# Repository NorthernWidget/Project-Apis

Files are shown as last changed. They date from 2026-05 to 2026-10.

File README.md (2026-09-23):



# Project-Apis
Design files for a support and interface unit for the Garmin LiDAR Lite.

## Contents

- [Namesake](#namesake)
- [Technical specifications](#technical-specifications)
  - [Electronic hardware](#electronic-hardware)
  - [Electronic software and firmware](#electronic-software-and-firmware)
- [Assembly](#assembly)
  - [Producing circuit boards](#producing-circuit-boards)
  - [Populating circuit boards](#populating-circuit-boards)
  - [Reflowing circuit boards](#reflowing-circuit-boards)
  - [Debugging circuit boards](#debugging-circuit-boards)
- [Firmware](#firmware)
  - [Downloading and installing the Arduino IDE](#downloading-and-installing-the-arduino-ide)
  - [AVR ISP](#avr-isp)
  - [Uploading the firmware](#uploading-the-firmware)
- [Writing a program to connect to the Apis](#writing-a-program-to-connect-to-the-apis)
  - [Very simple Arduino code](#very-simple-arduino-code)
  - [Northern Widget Margay code](#northern-widget-margay-code)
  - [Northern Widget Resnik code](#northern-widget-resnik-code)
- [Register map and firmware internals](#register-map-and-firmware-internals)
- [Housing and cabling](#housing-and-cabling)
  - [Parts required](#parts-required)
  - [Assembly](#assembly-1)
- [Field installation](#field-installation)
  - [Mast construction](#mast-construction)
- [Acknowledgments](#acknowledgments)

## Namesake

### Current: Apis

Rapid detector eyes

With its internal guidance system and compound eyes, the honeybee can obtain orientation and range while seeing in slow motion. Those rapid eyes feel perfect for a laser, and though the bee doesn't have one – it senses distance through parallax instead – just imagine if it did.

### Former: Symbiont-LiDAR

Symbiosis

***The symbiont.*** *Lichens, like this Reindeer Lichen found in northeastern
Minnesota, are a symbiosis between fungi and algae. Our symbiosis is between
silicon, copper, aluminum, and laser. But be it nature or machine, some
partnerships are truly mutual in their benefits. Photo by Homer Edward Price.*

The [LiDAR Lite](https://buy.garmin.com/en-US/US/p/578152/pn/010-01722-10) is a rangefinder from Garmin capable of returning distances to objects up to 40 m away. It is an effective sensor for water, snow, and ice levels, among other purposes. Extensive work to characterize the LiDAR Lite for environmental sensing of water levels has been performed by:

Paul, J. D., Buytaert, W., & Sah, N.(2020). A technical evaluation of lidar-based measurement of riverwater levels. *Water Resources Research*, *56*, e2019WR026810. https://doi.org/10.1029/2019WR026810

## Technical specifications

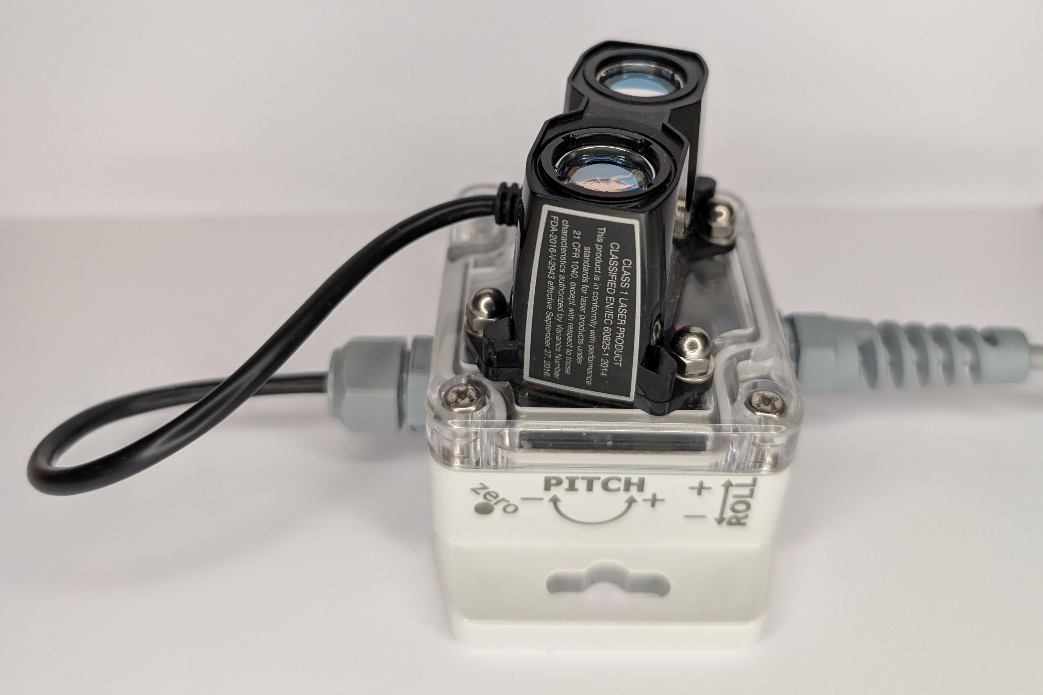
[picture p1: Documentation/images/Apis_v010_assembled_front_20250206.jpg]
Assembled Apis unit


***Assembled Apis unit.*** *The front face shows pitch and roll orientation conventions and the "zero" location (oval cutout, lower center) where the magnet is tapped to calibrate the accelerometer.*

### Electronic Hardware

* Microcontroller (computer) core
  * ATTiny1634
  * [Firmware](Firmware) written in Arduino-compatible C++
  * 12 MHz
* Sensors
  * Externally connected: [Garmin LiDAR Lite v3 HP](https://buy.garmin.com/en-US/US/p/578152/pn/010-01722-10)
  * On board
    * MEMS accelerometer to detect board angle
    * Hall-effect sensor to for user to trigger with a magnet after providing a known angle to the accelerometer. This corrects for offset errors in the accelerometer, significantly improving its angular accuracy.
* Connections and communications protocols
  * [LiDAR Lite v3 HP](https://buy.garmin.com/en-US/US/p/578152/pn/010-01722-10)
    * 6-pin screw-terminal header
    * Switchable 5V power supply
    * I2C
  * Data logger
    * Power in and Ground
    * Digital communications
      * I2C
* Power
  * Voltage limits: 3.3 ~ 5.5V
  * Power consumption: ~0.5mA @ 4.5V, take reading every 60 seconds, then power down
  * Power conditioning: Provides an onboard, high power, step up to 5V to allow for interface to 3.3V loggers
* Fault recovery: Using intermediate system to emulate an I2C connection prevents a global lockup of the logger system
* Status LED
* Open-source licensing via CC BY-SA 4.0

Apis board

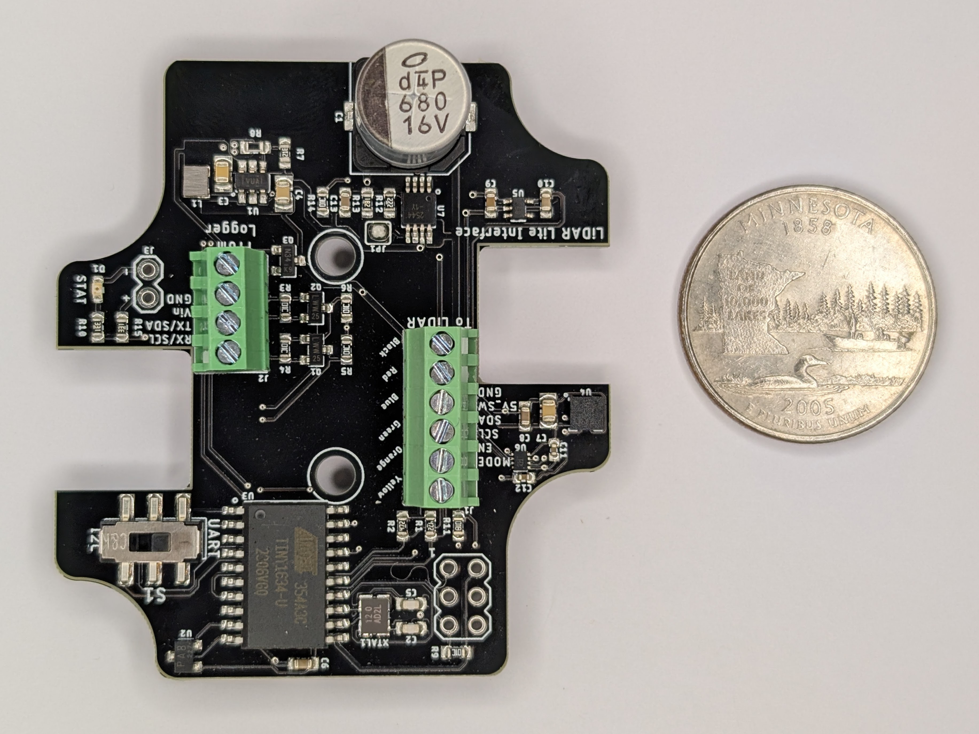
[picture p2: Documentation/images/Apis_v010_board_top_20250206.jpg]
Apis board top


***Apis v0.1 board, top side.*** *Minnesota quarter (24.3 mm diameter) for scale.*

### Electronic Software and Firmware

* Programmable using the Arduino IDE https://www.arduino.cc/en/main/software
* [Firmware](Firmware/Apis_LiDAR_Firmware) available in this repository.
* [Software](https://github.com/NorthernWidget/Apis_Library) to use the Apis with Arduino-compatible devices
* Open-source licensing via GNU GPL 3.0

## Assembly

Rendered image of assembled LiDAR unit

Assembling this sensor is possible by hand with sufficient skill and the following tools:
* Temperature-controlled soldering iron
* Hot-air rework station
* Equipment for stenciling with solder paste
* ESD-safe tweezers and workstation
* Solder wick

Most of the components on this board are coarse enough in pitch that assembly by hand is expected to be relatively straightforward. However, if you are concerned about this, there are PCB assembly workshops located in many parts of the world.

### Producing circuit boards

We recommend having circuit boards produced by a reputable manufacturer. Many are located in China, India, and other countries worldwide. You will need to provide the Gerber files, available in this repository alongside the board design files.

### Populating circuit boards

Before placing components, you will need solder paste and a stencil. A stencil allows you to apply a controlled, even amount of paste to all pads at once. If you have access to a laser cutter, you can [create your own stencil](https://learn.adafruit.com/smt-manufacturing/laser-cut-stencils); otherwise, most PCB manufacturers offer stencil production as an add-on service. In a pinch, a solder-paste syringe works but increases the risk of bridged connections. Additional guidance on stenciling is available [here](https://www.sparkfun.com/tutorials/58).

Once paste is applied, use tweezers – or a pick-and-place machine if available – to place each component onto its pads in the correct orientation. Slight misalignment is acceptable; surface tension from the molten solder will help pull components into place during reflow.

### Reflowing circuit boards

Reflowing heats the solder paste until it flows and bonds components to the board. A basic introduction is available [here](https://learn.sparkfun.com/tutorials/electronics-assembly/reflow). Common methods include:

1. **Professional reflow oven** – the most consistent method
2. **Converted toaster oven** – affordable and effective; see [SparkFun's guide](https://www.sparkfun.com/tutorials/60) and many other online references
3. **Electric skillet** – surprisingly effective for simple boards; [guide here](https://www.sparkfun.com/tutorials/59)
4. **Hot-air rework station** – more labor-intensive but gives fine control; suitable for single boards or small runs; [guide here](https://learn.sparkfun.com/tutorials/how-to-use-a-hot-air-rework-station/all)

After reflow, clean up any bridged connections with **solder wick**.

### Debugging circuit boards

Inspect the board carefully after reflow. Look for bridged connections, cold joints, or components that shifted out of alignment. A multimeter is essential for checking continuity and identifying shorts. An oscilloscope or logic analyzer can help verify that the microcontroller, accelerometer, and I2C bus are functioning correctly. If you are new to debugging circuit boards, working with an electrical engineering student or professional – even for a single session – can save significant time.

## Firmware

### Downloading and installing the Arduino IDE

Go to https://www.arduino.cc/en/main/software. Choose the proper IDE version for your computer. For Windows, we suggest the non-app version to have more control over Arduino; this might change in the future. You will have to add custom libraries, so the web version will not work (at least, as of the time of writing). Download and install the Arduino IDE. Open it to begin the next steps.

### AVR ISP

To install firmware on the Apis board, you use the [2x3-pin 6-pin ICSP (also called ISP) header](https://www.digikey.com/product-detail/en/3m/929665-09-03-I/3M156313-06-ND/681796) with a special device called an "in-circuit system programmer" (or just "in-system programmer; yup, that's what the acronym stands for).

Many devices exist to upload firmware, including:
* The official [AVR ISP mkII](http://ww1.microchip.com/downloads/en/DeviceDoc/Atmel-42093-AVR-ISP-mkII_UserGuide.pdf) (no longer produced but available used)
* Using an [Arduino as an ISP](https://www.arduino.cc/en/tutorial/arduinoISP)
* The versatile [Olimex AVR-ISP-MK2](https://www.olimex.com/Products/AVR/Programmers/AVR-ISP-MK2/open-source-hardware)
* The [Adafruit USBtinyISP](https://www.adafruit.com/product/46)

### Uploading the firmware

Using this ISP, upload [the firmware sketch](Firmware/Apis_LiDAR_Firmware) to the board. To do so, follow these steps:

1. Open the Arduino IDE.
2. Follow [these instructions](https://github.com/SpenceKonde/ATTinyCore/blob/master/Installation.md) to install the [ATTinyCore board definitions](https://github.com/SpenceKonde/ATTinyCore)
3. Select [ATTiny1634](https://github.com/SpenceKonde/ATTinyCore/blob/master/avr/extras/ATtiny_1634.md) **(No bootloader)**
4. Plug your ISP of choice into your computer (via a USB cable) and onto the 6-pin header. There are two ways to place it on; the header is aligned such that the ribbon cable should be facing away from the board while programming. If this fails without being able to upload, try flipping the header around. This should both power the board and provide communications.
5. Go to Tools --> Programmer and select the appropriate programmer based on what you are using.
6. Go to Tools --> Burn Bootloader. Yes, we know that you just selected "ATTiny1634 (No bootloader)", but this step sets the fuses, which configure their internal oscillator and brown-out detection.
7. Go to Sketch --> Upload Using Programmer. After several seconds, you learn whether you succeeded or failed. Hopefully it worked!

Upload using programmer

***Uploading using the in-system programmer.***

***Important note for Linux users:*** You must supply permissions to the Arduino IDE for it to be able to use the ICSP, or you will have to run it using `sudo`. The former option is better; the latter is easier in the moment.

***Note: Be sure to download and/or update drivers for your ISP.***

## Writing a program to connect to the Apis

Once it is bootloaded and connected with a LiDAR Lite sensor, you should be able to use any standard Arduino device to connect to it and read its data.

### Very simple Arduino code

This code is intended for any generic Arduino system.

```c++
#include "Apis.h"

// Declare variables -- just as strings
String header;
String data;

// Instantiate class
Apis myLaser;

void setup(){
    // Begin Serial connection to computer at 38400 baud
    Serial.begin(38400);
    // Obtain the header just once
    header = myLaser.getHeader();
    // Print the header to the serial monitor
    Serial.println(header);
}

void loop(){
    // Take one reading every (10 + time to take reading) seconds
    // and print it to the screen
    myLaser.updateMeasurements();
    data = myLaser.getString();
    Serial.println(data);
    delay(10000); // Wait 10 seconds before the next reading, inefficiently
}
```

### Northern Widget Margay code

The [Margay data logger](github.com/NorthernWidget-Skunkworks/Project-Margay) is the lightweight and low-power open-source data-logging option from Northern Widget. It saves data to a local SD card and includes on-board status measurements and a low-drift real-time clock. We have written [a library to interface with the Margay](github.com/NorthernWidget-Skunkworks/Margay_Library), which can in turn be used to link the Margay with sensors.

```c++
#include "Margay.h"
#include "Apis.h"

// Declare variables -- just as strings
// Empty header to start; will include sensor labels and information
String header = "";
String data;

// Instantiate classes
Apis myLaser;
Margay Logger; // Margay v2.2

// I2CVals for Apis
uint8_t I2CVals[] = {0x50}; // DEFAULT

//Number of seconds between readings
uint32_t updateRate = 60;

void setup(){
    header = header + myLaser.getHeader();
    Logger.begin(I2CVals, sizeof(I2CVals), header);
    initialize();
}

void loop(){
    Logger.run(update, updateRate);
}

String update() {
    initialize();
    return myLaser.getString();
}

void initialize(){
    myLaser.begin();
}
```

### Northern Widget Resnik code

>> The Resnik/Okapi system uses a Particle Boron for cellular telemetry – the defining capability that distinguishes it from the Margay. That telemetry component is not yet shown here; the code below is currently identical to the Margay example. See [issue #21](https://github.com/NorthernWidget/Project-Apis/issues/21).

```c++
#include "Resnik.h"
#include "Apis.h"

// Declare variables -- just as strings
// Empty header to start; will include sensor labels and information
String header;
String data;

// Instantiate classes
Apis myLaser;
Resnik Logger;

// I2CVals for Apis
uint8_t I2CVals[] = {0x50}; // DEFAULT

//Number of seconds between readings
uint32_t updateRate = 60;

void setup(){
    header = header + myLaser.getHeader();
    Logger.begin(I2CVals, sizeof(I2CVals), header);
    initialize();
}

void loop(){
    Logger.run(update, updateRate);
}

String update() {
    initialize();
    return myLaser.getString();
}

void initialize(){
    myLaser.begin();
}
```

## Register map and firmware internals

The Apis firmware runs on an ATTiny1634 and exposes an I2C register map to the host logger, laid out per [NW-Device-Specification](https://github.com/NorthernWidget/NW-Device-Specification) Schema 1. The default I2C address is `0x41` (ASCII `'A'`); the address is stored in Page 0 and can be changed (see below).

The device exposes a flat, byte-addressable virtual address space. The controller writes a 1-byte starting address, then reads up to 32 bytes in one transaction; the firmware auto-increments. Pages are 32-byte aligned.

The map below is what the firmware on `master` implements (firmware patch 5, unreleased). Boards carrying the previous firmware (v0.1.x, the deployed 2019-era map) are described at the end of this section; a Schema 1 library will refuse them until they are reflashed and provisioned.

### Measurement loop

The firmware is on-demand: it idles (core in idle sleep, woken by an I2C address match or the Hall switch) until the controller writes the trigger bit, then

1. Clears the ready bit, reads the chip-select bits from the control register, and consumes the trigger
2. If the controller has written the readings-requested word (0x44–0x45) since the last trigger, latches it and notes the reading counter
3. If the LiDAR chip is selected and the LiDAR is off: closes the 5 V switch, waits ~20 ms for the rail (680 µF through the MIC2544 at its ~227 mA limit), raises enable, and polls the LiDAR for an I2C acknowledge and the health flag in its STATUS register (bit 5) for up to 100 ms; on timeout toggles enable once more; a second failure powers the LiDAR down and latches fault chip 0 kind 1 (no acknowledge) or 5 (not initialised). On success it writes the configured sensitivity
4. If the LiDAR chip is selected and powered: writes ACQ_COMMAND (any non-zero value starts a measurement on the v3HP), polls STATUS bit 0 (busy) until clear, and reads the 16-bit range and the signal strength. The LiDAR's mode pin is not used (see issue #24)
5. If the accelerometer chip is selected: reads the 3-axis accelerometer (LIS3DH) and the stored offsets
6. Loads status, fault code, and the reading counter, then sets the ready bit, with interrupts disabled so a page read never straddles the update
7. Powers the LiDAR down if the request was for a single reading (0 or 1) or the requested count is now complete; otherwise leaves it powered for the next trigger. A batch with no trigger for 2 s is abandoned: LiDAR off, fault chip 0 kind 2

Serial output (range and axes per reading) exists only when the sketch is compiled with `APIS_DEBUG` defined.

### Register map (firmware on `master` – Schema 1)

Three 32-byte pages. Page 0 (identity) is copied from EEPROM at boot; Page 1 (calibration) is copied from EEPROM byte for byte at boot and again after each zero (a blank word reads as 0); Page 2 (status and sensor data) lives in SRAM. Pages renumbered 2026-09-23 (spec 4c3b18d): calibration is Page 1 at 0x20, data Page 2 at 0x40.

**Page 0 (0x00–0x1F) – Identity (EEPROM 0xC0–0xDF, written by [NW-Provision](https://github.com/NorthernWidget/NW-Provision))**

```
Block 0 (0x00–0x07)   Core identity
  0x00        0x01              Schema (NW-Device-Specification v1)
  0x01–0x04   'A','p','i','s'   Device name (ASCII)
  0x05–0x07   0x00,0x00,0x00    Null padding

Block 1 (0x08–0x0F)   Version
  0x08        HW major          (from EEPROM)
  0x09        HW minor          (from EEPROM)
  0x0A        FW patch          written by the firmware into the served copy (FW_FW_PATCH),
                                so it always matches the code running; the CRC of the served
                                copy is recomputed
  0x0B–0x0D   0x00,0x00,0x00    Unused (combined repo)
  0x0E–0x0F   0x00,0x00         Reserved

Block 2 (0x10–0x17)   Serial number
  0x10–0x11   0x41,0x00         Board type ('A' = 0x41, hardware major 0; NW-Registry 0x4100)
  0x12–0x13   [provisioning]    Group ID
  0x14–0x15   [provisioning]    Unique ID
  0x16–0x17   0x00,0x00         FirmwareID (legacy, reserved)

Block 3 (0x18–0x1F)   Integrity + administration
  0x18–0x1C   0x00 ×5           Reserved
  0x1D        0x4E              Magic byte ('N')
  0x1E        [computed]        CRC-8/SMBUS of bytes 0x00–0x1D
  0x1F        0x41              I2C address (writable; 0xFF = use default 0x41)
```

If the CRC in EEPROM does not match, or the schema byte is not 0x01, the firmware still runs but sets the Report register to "unit: Page 0 checksum" (`0xE3`); the board needs provisioning.

**Page 2 (0x40–0x5F) – Status and sensor data (SRAM)**

Chip table (index for status fault bits, control chip-select bits, and the Report register):

| Index | Chip | Measurements |
|---|---|---|
| 0 | LiDAR Lite v3HP | range, signal strength |
| 1 | LIS3DH accelerometer | X, Y, Z |

```
Block 0 (0x40–0x47)   Universal block (NW-Device-Specification)
  0x40        Status            bit 0 ready; bit 1 LiDAR fault; bit 2 accelerometer fault;
                                bit 7 pan-fault. Read-only, live.
  0x41        Control           writable. bit 0 trigger a reading now (the firmware clears it
                                when the reading starts); bit 1 measure LiDAR; bit 2 measure
                                accelerometer (power-up: both set); bit 7 sleep – defined by
                                the spec, not yet implemented here (cleared by the firmware).
                                Any write to Control clears the Report register.
  0x42–0x43   Reading counter   uint16, little-endian, +1 each time ready is set; 0 at boot
  0x44–0x45   Readings          writable, uint16 little-endian: how many readings the controller will
              requested         trigger with the LiDAR held powered; 0 (boot value) = one per trigger,
                                powered down after each. A new write replaces the remainder.
  0x46        Config            writable. bits 1:0 LiDAR sensitivity mode (see below)
  0x47        Report            latched until the controller writes Control: the most recent report, a fault (its chip's status bit is set too) or a notice (no status bit): bits 7-5 chip (7 = the unit), bits 4-0 kind (1 no acknowledge, 2 timeout, 5 not initialised, 6 reset, 9 calibration stored, 10 batch abandoned).
                                bits 7–5 chip (0 LiDAR, 1 accelerometer, 7 unit);
                                bits 4–0 kind (1 no-acknowledge, 2 timeout, 3 Page 0 checksum,
                                5 not initialised, 6 reset since the controller last wrote Control)

Block 1 (0x48–0x4F)   LiDAR Lite
  0x48–0x49   Range [cm]        little-endian int16; -9999 on timeout
  0x4A        Signal strength   uint8
  0x4B–0x4F   Reserved

Block 2 (0x50–0x57)   Accelerometer
  0x50–0x51   Accel X           little-endian int16 (raw counts, >> 4)
  0x52–0x53   Accel Y           little-endian int16
  0x54–0x55   Accel Z           little-endian int16
  0x56–0x57   Accel temperature, the LIS3DH OUT_ADC3 word as read (low byte first): relative, 1 digit per °C in the high byte (patch 3)

Block 3 (0x58–0x5F)   0x58–0x59 zero generation, uint16 LE, the Page 1 value, served with every reading (patch 5)
  0x5A–0x5F   Reserved
```

Check bit 0 of 0x40 before using any measurement; if clear, the data registers are stale. Compare the reading counter with the last value read to know whether a new reading has happened since.

At boot the Report register reads `0xE6`, "unit: reset since the controller last wrote Control", so a controller can tell that the device restarted (and lost its volatile configuration) since it last configured it. The first write to Control clears it.

**Page 1 (0x20–0x3F) – Calibration (EEPROM 0xE0–0xFF)**

```
Block 0 (0x20–0x27)   Current zero: Offset X, Y, Z int16 LE; accel temperature word int16   (as today)
  0x20–0x21   Offset X          little-endian int16
  0x22–0x23   Offset Y          little-endian int16
  0x24–0x25   Offset Z          little-endian int16
  0x26–0x27   Accel temperature word when the offsets were taken (patch 3)
Block 1 (0x28–0x2F)   Previous zero, same form
Block 2 (0x30–0x37)   The zero before that, same form
Block 3 (0x38–0x3F)   0x38–0x39 zero generation, uint16 LE: zeros stored since manufacture (0 = never);
                      0x3A–0x3F reserved
```

Offsets are written when the Hall-effect switch is triggered with the magnet (the board's "set level" action). A never-written word (0xFFFF) reads as zero. Storing a zero (patch 5) shifts Block 1 to Block 2 and Block 0 to Block 1, writes the new zero into Block 0, and adds one to the generation, byte by byte with compare-before-write; the served page and the mirror at 0x58 follow at once, and the Report register latches 0x29 (calibration stored) as before. Page 1 is stored in bus order from patch 5 (the earlier patches wrote the words big-endian), so a unit zeroed under patch 3 or 4 needs a new zero after reflashing.

### Sensitivity modes

Write one of the following values to the config register (`0x46`, bits 1:0) to set the LiDAR Lite measurement sensitivity:

| Value | Description |
|---|---|
| `0` | Balanced range and noise (default) |
| `1` | Higher sensitivity; reduced maximum range |
| `2` | Lower sensitivity; extended maximum range |
| `3` | Maximum range mode |

Configuration is volatile: the controller sets it after every power-up.

### I2C address

Page 0 byte `0x1F` holds the address; a write to register `0x1F` persists it (compare-before-write) and it takes effect on the next power cycle. `0xFF` means "use the default", `0x41`. Several Apis boards can share a bus by giving each its own address; choose one not listed in the NW-Device-Specification [bus-occupancy table](https://github.com/NorthernWidget/NW-Device-Specification#bus-occupancy).

### Firmware compatibility and detection

A Schema 1 library's `begin()` reads Page 0 Block 0 and refuses the device unless the schema byte is `0x01`, the name spells `Apis`, and the firmware patch at `0x0A` is at least the version the library was written for. A refused `begin()` means: reflash, then provision with NW-Provision. Check the return value of `begin()` when deploying.

### Previous register map (firmware v0.1.x, deployed 2019–2026)

A single 32-byte page, one byte served per request; status and identity mixed; no schema byte. Kept here for boards that have not been reflashed. Default address `0x50`.

| Address | Name | R/W | Description |
|---|---|-----|---|
| `0x00` | `REG_STATUS` | R | LiDAR initialised: `1` = ready, `0` = busy |
| `0x01`–`0x04` | `REG_NAME_0..3` | R | Device name: `'A'`,`'p'`,`'i'`,`'s'` |
| `0x05`–`0x07` | `REG_HW_MAJOR`, `REG_HW_MINOR`, `REG_FW_PATCH` | R | Versions (compiled in) |
| `0x08`–`0x09` | `REG_RANGE` | R | Range, little-endian int16 [cm] |
| `0x0A` | `REG_SIGNAL_STR` | R | LiDAR Lite signal strength (0–255) |
| `0x0B` | `REG_CONFIG` | R/W | Sensitivity mode [bits 1:0] |
| `0x0C` | `REG_I2C_ADDR` | W | Write to change I2C address (EEPROM byte 6) |
| `0x10`–`0x15` | `REG_ACCEL` | R | Accel X/Y/Z, three little-endian int16 values |
| `0x18`–`0x1D` | `REG_OFFSET` | R | Accel offsets X/Y/Z (EEPROM bytes 0–5) |

## Housing and cabling

### Parts required

This is what we used for our build; you can be creative based on materials and availability.

* Main enclosure
  * Polycase box [WC-20F (clear lid)](https://www.polycase.com/wc-20f)
  * [2x \#4 screws](https://www.polycase.com/screws-mbr-100) to mount Apis board in box
  * Cable gland ([Heyco M4365](https://www.heyco.com/Liquid_Tight_Cordgrips/product.cfm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)) for cable to LiDAR Lite
  * Strain-relieved cable gland ([Heyco M4425](https://www.heyco.com/Liquid_Tight_Cordgrips/product.cfm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)) for cable to logger
  * Desiccant packs
* LiDAR Rangefinder and attachment to enclosure
  * [LiDAR Lite sensor](https://www.sparkfun.com/products/14599)
  * [4 sealing screws](https://www.mcmaster.com/90825A144/): \#4-40 x 3/8"
  * [4 washers](https://www.mcmaster.com/90107A005) for \#4 screws
  * [4 cap nuts](https://www.mcmaster.com/99022A101) for \#4-40 screws
* Mounting plate
  * Material: Acetal (Delrin) sheet: 1/4" thick. We commmonly use [12x24" black](https://www.eplastics.com/ACTLBLK0-25012X24); the black pigment increases its UV resistance
  * Rectangular dimensions for mount: 127 x 95.25 x 6.35 mm (5.00" x 3.75" x 0.25")
  * [Design](https://easel.inventables.com/projects/VMmCoOyJyiiKTospk1NBBQ) on Easel for X-carve (see also [CNC files here](CNC)). Note the 7 mm depth to ensure that the bit cuts all the way through the Acetal; use a piece of scrap material on your cutting bed if you want to protect it.
* Mounting plate fasteners
  * 1/4"-20 hardware to attach the box to the mounting plate
    * Bolts: [1" long; hex head convenient; zinc-plated medium-grade (Grade 5) recommended for lower price with good corrosion resistance](https://www.mcmaster.com/92865A542)
    * Nuts: [Zinc-plated Grade 5](https://www.mcmaster.com/95462A029)
    * Washers: Zinc-plated [SAE](https://www.mcmaster.com/90126A029) or [USS](https://www.mcmaster.com/90108A413)
    * Lock washers: We typically use [split-lock washers](https://www.mcmaster.com/zinc-plated-steel-washers/), but [tooth-lock washers](https://www.mcmaster.com/91113A029) are good for high-vibration environments.
  * 2 U bolts: 1/4"-20, inner diameter 3/4" to 1 3/4", to attach the mounting plate to a pipe. We typically mount this sensor on 3/4" pipe or conduit, and recommend a U bolt designed to fit this ([1/4"-20, 1 1/8" inner diameter](https://www.mcmaster.com/u-bolts/u-bolts-with-mounting-plates/for-pipe-size~3-4/)). Weather/corrosion resistance is helpful, especially if you are concerned about later removing the U bolts.
* Cable to logger
  * 3 m (or less) [4-conductor AlphaWire](https://www.digikey.com/product-detail/en/alpha-wire/5004C-SL001/5004CSL001-ND/484976), stripped and tinned at both ends. Other cables will work too; this is what we have found to be highest quality and reliability. We cannot guarantee successful I<sup>2</sup>C communications over cables longer than 3 meters.

Mounting plate perspective view in Easel

***Mounting plate perspective view in [Easel](https://easel.inventables.com/projects/VMmCoOyJyiiKTospk1NBBQ)*** *for easy integration with the X-carve series of lower cost CNC routers.*

### Assembly

Prior to assembly, ensure that you have:
* [Uploaded the firmware to the Apis board](#Uploading-the-firmware)
* Fabricated [the mounting plate](CNC) (see also the [Easel online CNC setup](https://easel.inventables.com/projects/VMmCoOyJyiiKTospk1NBBQ)) if desired.

1. Drill and tap 12 mm holes in the side of the box. Use a M12-1.5 tap for the threads.

2. Install the Apis board as shown below using two of the \#4 self-tapping screws.

Apis prototype in box

3. Using the sealing screws, cap nuts, and washers, install the LiDAR Lite sensor onto the lid. By mounting the LiDAR Lite at an angle, you can fix it to the box lid in a way that still allows the box to open and close properly. The cap nuts go on the outside of the housing.

Prototype sensor assembly

4. Thread the cables through the cable glands and attach them to the screw terminals. A 1.8 mm flat-head screwdriver can be very useful for this. Note that these cables cross the board in the above image (upper left) -- and that (unlike in the image!) you should do this *after* the board is in the box.

5. Using the switch in the box, select the desired communications protocol. For most of our uses, this is I2C.

6. Attach the cable to the data logger.

7. Test the LiDAR Lite unit.

8. When satisfied with the tests, turn off the data logger and place a protective cover over the lenses of the LiDAR Lite for safety during transport. We have [a set of "safety glasses" available for 3D printing](3Dprint). You may want to secure these in place with electrical tape.

9. Place desiccant in the box. I typically install two small desiccant packs on the side of the board above the switch and large capacitor and pack them in so they are unlikely to move; this is in order to keep the indicator LED visible.

10. Securely screw the lid onto the box to seal the LiDAR Lite + Apis unit.

11. Mark the corner of the box next to the Hall-effect sensor, and mark the orientations of the roll and pitch axes. The pitch axis should be positive when the long strain-relieved cable gland tilts upwards. The roll axis should be positive when, when looking at the side of the assembly such that the long strain-relieved cable gland is on the left and the laser rangefinder is pointed up, the laser rangefinder rolls towards you.

Side view: long axis, with pitch +/- marked

Side view: short axis, LiDAR Lite cable, with roll +/- marked

Assembled Apis unit showing pitch, roll, and Hall-effect zero location

***Pitch, roll, and Hall-effect calibration location on the assembled unit.*** *The "zero" oval cutout on the lower center of the box face marks where to tap the magnet.*

12. Place the box on a measured flat surface and tap the magnet to the marked location by the Hall Effect sensor. This will appropriately zero the offsets for the sensor and increase its near-horizontal accuracy significantly. This must be done when the sensor is powered. From firmware patch 3 the magnet only starts the zero: tap it at the mark, at boot or at any time, and take it away. The LED lights and stays on while the firmware averages samples at the accelerometer's 10 Hz rate until the mean of every axis has settled (at least 3.2 s, at most 100 s), and goes out when the zero and its temperature are stored. Keep the unit still until then. From patch 5 the unit keeps the two zeros before the current one, with a count of zeros stored since manufacture that every reading carries, so a logger can tell when a zero was retaken. When connected to a logger, hold the magnet at the mark, hit the "RESET" button (e.g., on a Margay logger), and remove the magnet once the LED is on. Doing this while connected to a computer is recommended in order to see the first reading on the serial monitor and double check that the zeroing/calibration is appropriate. For a convenient magnet holder, you can use our [3D-printable magnetic wand][3Dprint], which holds a small rare-Earth magnet. This may be a generic part, though this [3/8" x 1/8" Neodymium Disk Magnet](https://www.apexmagnets.com/magnets/3-8-x-1-8-disc-neodymium-magnet) works well in our experience.

13. Use the 1/4"-20 hardware to attach the LiDAR Lite box to the mounting plate. The bolts pass through the center holes on the tabs on either side of the box, with their heads towards the box lids.

>> Note: Mounting plate holes currently too small for these; will need to be updated. Currently using #8 hardware. Figures for pitch+roll have 1/4-20 -- I probably drilled it out wider for these.

14. (Can wait for field installation) attach the unit via its mounting plate to the appropriate pipe, post, etc. This typically involves the U bolts, noted above. Curved EMT conduit can be helpful for providing a way to select the angle of the sensor. Although we use a single 45-degree bend piece of conduit in the images below, we might suggest attaching a 90-degree bend conduit first, and then a 45-degree bend as necessary to adjust the sensor away from a direct down-looking view; the sensor will attach directly to the convex side of the bend instead of bridging over airspace, which required us to use rocks as shims to reduce mounting-plate flexure. (This suggestion, however, increases torque on the mast; future field testing is needed to determine the best method.) ***Note: The LiDAR Lite unit will likely give a return only if its angle to the surface that it is measuring is steeper (i.e., more orthogonal) than 45 degrees.***

Field installation prototype in the lab: Sensor only

## Field installation

Field installation prototype in the lab

***Lab mock-up of field installation for LiDAR Lite.*** *The boxes at right contain [Northern Widget Margay](https://github.com/NorthernWidget-Skunkworks/Project-Margay) data loggers with a single cable gland to connect to the Apis box. The two posts next to them provide examples of how to connect the 3/4" EMT conduit to some fixed point in the environment, either the side of a flat(ish) wall (right) -- though the brackets aren't necessary or even always good, since we can bolt right through the pipe -- or to a flat(ish) surface using a floor flange. We drilled holes through the conduit to attach 1/4" eye bolts (1/4"-20, 1.5" long) using nuts, lock washers, and washers, to the conduit. These eye bolts then held turnbuckles to which we attached cables (lower left). The other end of the cables can be attached via sleeve or wedge anchors to rock, or to other sturdy structures. The LiDAR Lite + Apis is in the upper left corner, albeit attached in a way that would have it looking up... unless it were attached to the end of the 90-degree bend.*

### Mast construction

#### Supplies

* 3/4" EMT rigid conduit
  * Straight: main mast
  * 90-degree bend
  * 45-degree bend
* 3/4" Conduit screw-down connectors (to join multiple pieces of conduit)
* 3/4" Conduit-to-threaded connectors (to link smooth conduit to threaded 3/4" plumbing, needed only if you use a floor flange)
* Floor flange (1, if you want to attach to a flat surface)
* 1/4-20 x 1.5" eye bolts (3, +1 in case you bend/break one)
* 1/4" x 2+" long sleeve or wedge anchors; 4 for the floor flange or 2 for bolting into the side of a rock. Extras suggested, as these can be broken during installation.
* Turnbuckles; I suggest getting 3 that are threaded all the way down (as shown in the picture above). Get an extra in case you break one.
* 1/8" metal cable
* 1/8" cable clamps (x6, +1 in case you lose the nuts)
* 1/8" metal cable turns (x6; if you lose one, don't worry; these are nice for durability but not totally necessary)
* 3/8" x 2.5+" long sleeve or wedge anchors for the cables; these are less breakable than their 1/4" cousins, but you might still want an extra one.
* Extra 1/4"-20 hardware. I almost always end up needing this.
* Cable management (keep secure and prevent from flapping in the wind, which can cause damage)
  * Cable ties (zip ties). Ensure that these are UV-resistant; many black ones are.
  * Electrical tape
* *Optional:* 2x ~1-3/4" hose clamps if mounting a data-logger box for the [Margay](https://github.com/NorthernWidget-Skunkworks/Project-Margay) on the main mast. Longer hose clamps (or multiple 1-3/4" clamps in series) for larger logger boxes, so long as they can remain stable on the mast.

You might not need the guy wires and associated hardware if you bolt your assembly to the side of something (like a rock or wall). Some guy wires are generally encouraged.

#### Assembly

Leveling the base
***Placing and leveling the base.***

Base is installed using wedge anchors
***Installing the base using wedge anchors.***

Conduit installed and anchored with eye bolts and turbuckles.
***Installing the conduit and anchoring it with eye bolts and turnbuckles.*** *Before going out to the field, we strongly suggest you pre-drill the holes and pre-install the eye bolts.*

Cable to rock bolt
***Tightening the cable around the bolt in the rock using the cable clamp.***

Aiming the LiDAR Lite
***Aiming the LiDAR Lite unit at the river.*** *In future models, we are considering adding peep sights to the mounting bracket. [Professor Billy Armstrong](https://earth.appstate.edu/faculty-staff/dr-william-h-armstrong) in the photo.*

The quality of any zeroing with the Hall-effect sensor is limited by the accelerometer itself: from firmware patch 3 the zero is an average with about 0.01° of noise, but the LIS3DH's offset drifts by about 0.5 mg per °C, which is about 1.7° across a 60 K season after the zero. The chip's temperature is logged beside pitch and roll (the `AccelT` column) so that a per-unit correction can be fitted once bench data exist; until then, measure and record the orientation of the field-mounted unit by hand as an additional check. The survey behind these numbers is in the private repository NorthernWidget-Skunkworks/Inclinometer-Selection.

Perspective view upvalley
***Fully installed clifftop unit***

Perspective view after installation.
***Fully installed clifftop unit*** *Note data-logger box attached with cable ties, as well as the mounting-plate attachment. For the latter, we used a rock as a shim with a 45-degree piece of EMS conduit. However, it may have been better to use a 90-degree piece of conduit and a 45-degree piece of conduit together to keep us from needing this shim -- though this would have increased torque on the main mast.*


***Alternative method: installing on the side of a rock.***

Culvert deployment with context
***Full mast installed on the side of a rock.*** *Note the LiDAR Lite + Apis and the data-logger box.

## Legacy identity

Units programmed before Schema 1 carry board type `0x6C00` (the Symbiont-LiDAR code) in the old 8-byte serial block and answer at I²C address `0x50`. They are refused by a Schema 1 library until reflashed and provisioned; see [Register map and firmware internals](#register-map-and-firmware-internals).

## Acknowledgments

Support for this project provided by:

UMN ESCI

WMO

<br/>
<br/>
<br />This work is licensed under a <a rel="license" href="http://creativecommons.org/licenses/by-sa/4.0/">Creative Commons Attribution-ShareAlike 4.0 International License</a>.

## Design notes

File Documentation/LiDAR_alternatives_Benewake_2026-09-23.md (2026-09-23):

# LiDAR-Lite v3HP replacement: Benewake TF-series evaluation (2026-09-23)

Research report produced with Claude on 2026-09-23 at Andy Wickert's request after a Benewake sales contact. Every figure carries a source key; items marked UNVERIFIED are not sourced. Decision: none yet.

Research is complete; everything below was read from the manufacturer PDFs I downloaded and text-extracted in this session (`pdftotext`), plus the distributor pages that allowed fetching. Nothing is from memory except where marked UNVERIFIED.

# Benewake TF-series as a LIDAR-Lite v3HP replacement for Apis

## 1. Comparison table

Source keys are listed at the end; every figure carries one. "—" = not stated in that source.

| | **LIDAR-Lite v3HP** [G] | **TF02-Pro** [P] | **TF03-100 / -180** [T3] | **TF350** [T350] | **TFmini Plus** [MP][MP2] | **TFmini-S** [MS][MS2] | **TF-Luna** [L][L2] | **TFS20-L** (2024) [S20] | **TF-Nova** (2024, line laser) [N] |
|---|---|---|---|---|---|---|---|---|---|
| Range, 90 % target | 40 m (spec'd at 70 %) | 0.1–40 m; same at 100 klux | 0.1–100/180 m; 80/130 m at 100 klux | 0.2–350 m; 300 m at 100 klux | 0.1–12 m; same at 70 klux | 0.1–12 m | 0.2–8 m | 0.2–20 m; 18 m at 100 klux | ≥14 m; ≥7 m at 100 klux |
| Range, 10 % target (dark) | — | 0.1–13.5 m | 40/70 m; 30/50 m at 100 klux | 110 m; 100 m at 100 klux | 0.1–4 m | 0.1–7 m | 0.2–2.5 m | 18 m; 12 m at 100 klux | ≥13 m; ≥4 m at 100 klux |
| ArduPilot "reliable max" [AP] | — | 13.5 m | 50 m | 150 m | — | — | 8 m | 15 m | 7 m |
| Accuracy / resolution | ±2.5 cm typ ≥2 m, ±5 cm <2 m; 1 cm | ±5 cm (<5 m), ±1 % (5–40 m); 1 cm; 1σ <2 cm | ±10 cm (<10 m), 1 %; 1 cm; 1σ <3 cm | ±10 cm (<10 m), 1 %; 1σ <3 cm | ±5 cm (<5 m), ±1 %; 1 cm | ±6 cm (<6 m), ±1 % | ±6 cm (<3 m), ±2 % | ±6 cm (<6 m), 1 % | ±5 cm (0.1–4 m) |
| Frame rate | >1 kHz | 1–1000 Hz (default 100) | 1–1000 Hz (7 kHz custom) | 1–1000 Hz (10 kHz custom) | 1–1000 Hz | 1–1000 Hz | 1–250 Hz | ≤250 Hz | 1–900 Hz |
| Single-shot / on-demand | Yes: write 0x04→reg 0x00, read 0x0F/0x10 | Yes: frame rate 0, then `5A 04 04 62`; I²C on-demand read `5A 05 00 01 60` → 9 B | Yes: trigger mode `5A 04 04 62` | Yes (trigger mode) [T350 refers to manual] | Yes, same commands as TF02-Pro | Yes, same | Yes: I²C reg 0x24 TRIG_ONE_SHOT; ultra-low-power wake-on-read | — (UART/I²C, 0x10) | I²C regs like TF-Luna |
| Interfaces / address | I²C 0x62 (changeable), PWM, trigger | UART 115200 or I²C 0x10 (0x01–0x7F), I/O | UART/CAN (std), RS485/RS232, 4–20 mA; **no I²C** [T3][AP] | UART/CAN or RS485/RS232; **no I²C** | UART / I²C 0x10 / I/O | UART / I²C 0x10 | UART / I²C 0x10 (pin-5 select) | UART / I²C 0x10 | UART / I²C 0x10 |
| Supply / current | 4.5–5.5 V; 65 mA idle, 85 mA acquiring; power-enable pin | 5–12 V; ≤200 mA avg, 300 mA pk, ≤1 W; low-power mode ≤10 Hz (current not stated) | 5–24 V; ≤150 mA @5 V, ≤1 W; low-power 5 Hz 150 mW **UART only** | 5–24 V; ≤150 mA @5 V, ≤1 W | 5 V ±0.5; ≤110 mA, 140 mA pk, 550 mW; low-power <100 mW ≤10 Hz | 5 V ±0.1; ≤140 mA, 200 mA pk | 3.7–5.2 V; ≤70 mA; ECO 8.85 mA @1 Hz; sleep 1.5 mW | 3.3 V ±9 %; ≤0.35 W, 115 mA pk | 5 V ±5 %; <500 mW; 850 mA start pk |
| Operating temp | −20…60 °C | −20…60 °C | −25…60 °C | −25…60 °C | −20…60 °C | 0…60 °C | −10…60 °C | −20…60 °C | −25…70 °C |
| IP rating / housing | IPX7 | IP65, ABS/PC | IP67, aluminium, IR glass window | IP67, aluminium | IP65, PC/ABS | none ("/") | none stated | none (bare module) | front window IP65, body N.A. |
| Size / mass | 40.2×55×35 mm, 38 g | 69×41.5×26 mm, 50 g, 80 cm cable | 44×43×32 mm, 86–92 g, 70 cm cable, Molex 51021-07 | 78×67×40 mm, 222 g | 35×18.5×21 mm, 12 g | 42×15×16 mm, 5 g | 35×21.25×13.5 mm, <5 g | 21×15×7.9 mm, 1.35 g | 26.5×21×12 mm, <5 g |
| Laser | 905 nm, Class 1 | 850 nm VCSEL, Class 1 | 905 nm LD, Class 1 | 905 nm LD, Class 1 | 850 nm, Class 1 | 850 nm, Class 1 | 850 nm, Class 1 | 905 nm, Class 1 | 905 nm, Class 1 |
| Price (2026‑09‑23) | $169.99, in stock [G2] | $87.90 (9 left) [DF]; $99.90 [SL] | $269 UART/CAN, $299 RS485 [SL] | $599 UART [SL] | $49.90 [SL] | — | $29.90 [SL] | $49.90 [SL] | $39.95 SparkFun [SF] |
| Arduino library | Garmin LIDARLite | none TF02-Pro-specific found; protocol identical to TFmini Plus | none found | none found | budryerson/TFMini-Plus-I2C [LIB1] | same [LIB1] | budryerson/TFLuna-I2C [LIB2] | none found | none found |

## 2. Ranked recommendation

**1. TF02-Pro, I²C variant.** The only Benewake unit that matches the 40 m spec, runs on Apis's switched 5 V, and speaks I²C. Board: no supply change (5–12 V in, so the 5 V switch stays); replace the Garmin connector with the TF02-Pro's 4-wire pigtail (connector type not stated in the manual – UNVERIFIED). Firmware: the ATtiny1634 swaps Garmin register writes for Benewake's `0x5A` command frames – on power-up send `5A 06 03 00 00` (frame rate 0 → trigger mode) once and `5A 04 11 6F` (save), then per reading `5A 04 04 62` followed by `5A 05 00 01 60` and a 9-byte read (dist, strength, temperature, checksum). Address is 0x10, changeable (0x01–0x7F) if it collides on the NW bus. Costs: 10 %-target range is 13.5 m, not 40 m; accuracy ±1 % beyond 5 m (±40 cm at 40 m) vs Garmin ±2.5 cm typ; 1 W while on vs 0.4 W; IP65 plastic vs IPX7; start-up-to-first-valid-frame time not stated (UNVERIFIED, must be measured – it sets the energy per sample).

**2. TF03-100, UART variant.** If dark targets at 30–40 m or a metal IP67 housing matter, this is the only Benewake with the margin (40 m at 10 %, 30 m at 100 klux). Board: 5 V still works and it draws *less* (≤150 mA) than the TF02-Pro; needs the 7-pin Molex 51021. Firmware: ATtiny1634 talks UART 115200 (it has hardware USARTs) using the same command set, and bridges to the host's I²C – a larger firmware change but the host interface is unchanged. Costs: $269, 90 g, ±10 cm/1 %, 0.5° beam.

**3. TFmini Plus, I²C variant – short sites only.** Same protocol and library as TF02-Pro, IP65, −20…60 °C, <100 mW low-power mode, $50. Only for installs within ~10 m over bright targets (4 m at 10 %). Not a general v3HP replacement.

Not recommended: TF-Luna, TFmini-S, TFS20-L (unsealed, −10/0 °C minimum for two of them, ≤8–20 m); TF-Nova (line beam, 7 m outdoors, though Benewake markets it for liquid level [BW]); TF350 (overkill, $599, 222 g); TF02-Pro-W (IP5X wiper unit for bulk solids).

## 3. Concerns

- **Water surfaces.** Neither vendor gives a range figure to water. Benewake's TF02-Pro/TFmini manuals list "transparent substance (such as glass and water)" as a cause of data errors [P][MP]; Garmin's manual says a flat specular surface may return nothing unless viewed from the normal and that ripples help [G]. The TF02-Pro's 3° beam (≈2 m spot at 40 m) versus Garmin's 8 mrad may average ripples differently – untested, UNVERIFIED either way. Bench the candidate over a real pool before committing.
- **Snow.** No Benewake snow-depth reports found. Fresh snow is a bright diffuse target at 850–905 nm (general knowledge, UNVERIFIED here), so the 90 % column applies; wet or dirty snow trends toward the 10 % column.
- **Sunlight.** Benewake specifies 100 klux (70 klux for TFmini Plus); Garmin gives no number, so the comparison is one-sided.
- **Minimum range** 0.1 m vs Garmin 5 cm – irrelevant at 0.5 m mounting.
- **Energy per reading.** TF02-Pro's low-power mode caps at 10 Hz but states no current; TF03's low-power mode is UART-only. Since Apis cuts power between samples, wake-up time matters more than any sleep mode, and it is unstated for TF02-Pro/TF03.
- **Pricing/MOQ.** Single-unit purchase is verified at DFRobot, SensorLiDAR, SparkFun (TF-Nova); Mouser lists all models but its pages timed out, so Mouser pricing and lead times are UNVERIFIED; no MOQ or volume tiers were found anywhere – ask Benewake directly.
- **Garmin status.** The premise "discontinued" is not confirmed: SparkFun shows the v3HP in stock at $169.99 today and no EOL notice was found [G2]. If it remains available, it is still the better sensor for this job on accuracy, IPX7, and power; Benewake's case is price ($88–100) and I²C-compatible fallback, not performance.

**Other alternatives (one paragraph).** LightWare LW20/C: 100 m, I²C or serial, IP67, $299.30 at DigiKey [DK2]; the open-frame SF20/C is $279 but unsealed, −10…50 °C, 0 in stock with 16-week lead [DK1]. LightWare claims first/last-pulse operation in rain/snow and "over water" in marketing copy only (UNVERIFIED figure). Garmin's own LIDAR-Lite v4 LED is a 10 m device and does not cover 40 m (UNVERIFIED, from memory). Industrial units (SICK DT50, Baumer) reach 40 m+ but need 24 V and cost several hundred dollars (UNVERIFIED).

## 4. Unverified list
TF02-Pro connector type and start-up time; TF02-Pro low-power current; Mouser prices/lead times; MOQ/volume tiers; snow reflectance statement; LightWare water claim; Garmin v4 LED range; industrial-sensor pricing; SensorLiDAR's relationship to Benewake.

## Sources
[G] https://static.garmin.com/pumac/LIDAR-Lite_v3HP_Instructions_EN.pdf · [G2] https://www.sparkfun.com/lidar-lite-v3hp.html · [P] https://en.benewake.com/uploadfiles/2024/04/20240426135442695.pdf · [T3] https://en.benewake.com/uploadfiles/2024/04/20240426134845102.pdf · [T350] https://doc.switch-science.com/media/files/fcfd4ded-16ff-4486-acad-a5217d66774f.pdf · [MP] https://en.benewake.com/uploadfiles/2024/04/20240426135807930.pdf · [MP2] https://www.makerguides.com/wp-content/uploads/2024/12/TFmini-Plus-datasheet.pdf · [MS] https://en.benewake.com/uploadfiles/2024/04/20240426140053930.pdf · [MS2] https://www.gotronic.fr/pj2-sj-gu-tfmini-s-01-a00-datasheet-2154.pdf · [L] https://en.benewake.com/uploadfiles/2024/04/20240426135946148.pdf · [L2] https://s3-us-west-2.amazonaws.com/files.seeedstudio.com/products/101990656/res/SJ-GU-TF-luna-A01+Datasheet.pdf · [S20] https://en.benewake.com/uploadfiles/2024/08/20240821162819250.pdf · [N] https://dfimg.dfrobot.com/wiki/18669/SEN0671_tf-nova-line-laser-lidar-sensor_datasheet_V.pdf · [AP] https://ardupilot.org/copter/docs/common-benewake-tf02-lidar.html · [BW] https://en.benewake.com/NewsUpdates/info_itemid_2149.html · [DF] https://www.dfrobot.com/product-1599.html · [SL] https://www.sensorlidar.com/products/benewake-tf02-pro-40m-ip65-lidar-sensor , …/benewake-tf03-100-long-range-ip67-lidar , …/benewake-tf350-long-range-industrial-lidar , …/benewake-tfmini-plus-lidar-ip65-12m-tof-sensor , …/benewake-tf-luna-8m-lidar , …/benewake-tfs20-l-mini-dtof-lidar-20m · [SF] https://www.sparkfun.com/benewake-tf-nova.html · [DK1] https://www.digikey.com/en/products/detail/lightware-lidar-inc/SF20-C/15848650 · [DK2] https://www.digikey.com/en/products/detail/lightware-lidar-inc/LW20-C/15848653 · [LIB1] https://github.com/budryerson/TFMini-Plus-I2C · [LIB2] https://github.com/budryerson/TFLuna-I2C

Extracted datasheet text is in `/tmp/claude-1000/-home-awickert-Dropbox-NorthernWidget-github/7a629d90-8ea9-4f47-b3c2-74b2c03d2dcd/scratchpad/pdf/` if the caller wants to check any figure against the source.

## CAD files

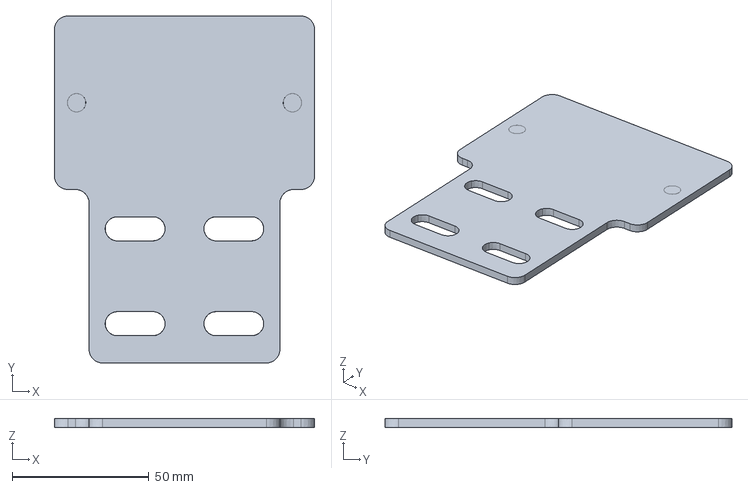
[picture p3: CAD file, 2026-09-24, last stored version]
CNC/ApisMountPlate2025_v2.FCStd
95.2 x 127.0 x 3.20 mm

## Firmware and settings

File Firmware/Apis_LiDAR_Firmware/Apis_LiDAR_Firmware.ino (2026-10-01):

#include "SlowSoftI2CMaster.h"
#include "WireS.h"
#include <avr/sleep.h>
#include <EEPROM.h>
// #include <EEPROM.h> //DEBUG!

// Commands
#define CTRL_REG1_ADR 0x20
#define CTRL_REG2_ADR 0x21
#define CTRL_REG3_ADR 0x22
#define CTRL_REG4_ADR 0x23
#define TEMP_CFG_REG_ADR 0x1F
#define OUT_X_ADR 0x28 //Low byte
#define OUT_ADC3_ADR 0x0C //Auxiliary ADC channel 3, low byte: the temperature sensor when TEMP_EN is set
#define STATUS_REG_ADR 0x27
#define OUT_Y_ADR 0x2A
#define OUT_Z_ADR 0x2C

// Pin definitions
#define POWER_SW 2
#define ACCEL_INT 7 //Interrupt from accelerometer, active low, needs internal pullup
#define MODE_TRIGGER 13 //Trigger for pulse width mode
#define MODE_READ 11 //Read pin for pulse width mode, also INTO
#define STAT_LED 14 //Status LED
#define HALL_SWITCH 8 //Hall effect switch output 
#define ENABLE 4 //Enable pin for Lidar Lite


// #define ACCEL_ADR 0x18
const int ACCEL_ADR = 0x18; //DEBUG!

#define LIDAR_ADR 0x62

// Serial output (range and accelerometer axes per reading) only in debug builds:
// TX/RX are not used in normal operation (ICSP-only), and the prints cost ~25 ms
// per reading at 9600 baud.
// #define APIS_DEBUG

#define READ 0x01
#define WRITE 0x00

#define BUF_LENABLEGTH 64 //Length of I2C Buffer, verify with documentation

// Firmware patch version: bump on any behavioural change visible to the
// library. The hardware version lives in Page 0 (EEPROM), written at
// provisioning; the firmware writes this constant into the served copy of
// Page 0 at 0x0A and recomputes the CRC there (NW-Device-Specification).
#define FW_FW_PATCH 5
#ifndef FW_COMMIT
#define FW_COMMIT ""  // Set by the build wrapper (NW-Build) as -DFW_COMMIT="a1b2c3d4+"; blank in an IDE build
#endif

// The stored pages are the top 64 bytes of EEPROM in bus order: Page 0
// (identity, 32 bytes) at 0xC0-0xDF on the ATtiny1634's 256-byte EEPROM,
// written once by NW-Provision and read at boot; Page 1 (calibration)
// directly above it at 0xE0-0xFF, in bus order (little-endian words), served
// byte for byte: Block 0 the current zero (offsets X, Y, Z and the
// temperature word), Blocks 1 and 2 the two zeros before it, 0x38-0x39 the
// zero generation (patch 5). A blank word (0xFFFF) is served as 0.
#define PAGE0_BASE   (E2END + 1 - 64)
#define REG_I2C_ADDR 0x1F
#define PAGE1_BASE   (E2END + 1 - 32)
#define ADR_DEFAULT  0x41   // Schema 1 'A'; used when Page 0 byte 0x1F is 0xFF

// #define ADR_ALT 0x41 //Alternative device address

const unsigned long timeoutGlobal = 200; //Time to wait before timing out

bool lidarFail = false; //Used to indicate failure of Lidar unit
bool accelFail = false; //Used to indicate failure of on board accelerometer 

volatile uint8_t adr = ADR_DEFAULT; //I2C address: Page 0 byte 0x1F (EEPROM), or ADR_DEFAULT if unprogrammed
// const uint8_t ADR_Alt = 0x41; //Alternative device address  //WARNING! When a #define is used instead, problems are caused
// NOTE: Switching to 0x41 via a solder jumper requires a board revision to
// add address-selection hardware; no such circuit exists in the current design
// (JP1 is the MIC2544 current-limit jumper, not an address jumper).
// The I2C address is Page 0 byte 0x1F (EEPROM 0xDF), written via register
// 0x1F; read in setup() before Wire.begin(). Falls back to ADR_DEFAULT if 0xFF.

unsigned int config = 0; //Global config value
// On-demand run model (NW-Device-Specification, Apis appendix): the unit idles until a
// trigger. The LiDAR is powered only while readings are being taken, per the
// readings-requested word (0x44-0x45): up at the first trigger, down when the
// requested count is done. No idle timer; a batch that stalls is abandoned.
bool lidarOn = false; //LiDAR powered and configured
uint16_t requested = 0; //readings-requested word, latched at the first trigger after a write
uint16_t requestBase = 0; //reading counter when the request was latched (internal, not a register)
volatile bool requestWritten = false; //set by receiveEvent() on a write to 0x44/0x45
unsigned long lidarLastReading = 0; //millis() of the last reading while powered
const unsigned long lidarBatchTimeout = 2000; // ms without a trigger before a batch is abandoned (fault fallback)
uint8_t lidarConfigApplied = 0xFF; //Config bits last written to the LiDAR
uint8_t lidarInitFail = 0; //fault code if the last power-up failed, else 0
const unsigned long lidarRailMs = 20; //rail ramp before enable: 680 uF via the MIC2544 at ~227 mA is ~15 ms
const unsigned long lidarBootTimeout = 100; // ms to wait for ACK + health after enable (manual: ~22 ms)

// Page 0 (0x00–0x1F) identity is copied from EEPROM at boot (loadPage0);
// Page 1 (0x20–0x3F) calibration and Page 2 (0x40–0x5F) sensor data per
// NW-Device-Specification Schema 1 (Apis appendix; pages renumbered
// 2026-09-23, spec 4c3b18d: calibration is Page 1, data Page 2).
//   0x20–0x25   Accelerometer offsets X, Y, Z, little-endian int16 each (Page 1)
//   0x26–0x27   Accelerometer temperature word when the offsets were taken (Page 1)
//   0x28–0x2F   The previous zero, same form; 0x30–0x37 the one before that (Page 1, patch 5)
//   0x38–0x39   Zero generation, uint16 little-endian: zeros stored since manufacture, 0 never (Page 1, patch 5)
//   0x40        Status: bit 0 ready (registers hold a complete reading);
//               bit 1 LiDAR fault; bit 2 accelerometer fault; bit 7 pan-fault
//   0x41        Control (writable): bit 0 trigger a reading now (self-clearing);
//               bit 1 measure LiDAR, bit 2 measure accelerometer, on the next
//               reading (power-up: both set); bit 7 sleep (reserved here; the
//               firmware clears it; implementation deferred)
//   0x42–0x43   Reading counter, uint16 little-endian, +1 when ready is set
//   0x44–0x45   Readings requested, uint16 little-endian (writable)
//   0x46        Config (writable): sensitivity mode bits [1:0]
//   0x47        Report, latched until the controller writes Control: the
//               device's most recent report, a fault (its chip's status bit
//               is set too) or a notice (no status bit):
//               bits 7–5 chip (0 LiDAR, 1 accelerometer, 7 the unit), bits 4–0 kind
//               (1 no-acknowledge, 2 timeout, 5 not initialised, 6 reset,
//               9 calibration stored, 10 batch abandoned)
//   0x48–0x49   Range [cm], little-endian int16
//   0x4A        LiDAR Lite signal strength (uint8_t, from LiDAR Lite reg 0x0E)
//   0x50–0x55   Accelerometer X, Y, Z raw, little-endian int16 each
//   0x56–0x57   Accelerometer temperature, the LIS3DH OUT_ADC3 word as read (L, H), relative, 1 digit/°C in the high byte
//   0x58–0x59   Zero generation again, the Page 1 word mirrored so that a reading carries it (patch 5)
#define REG_OFFSET   0x20
#define REG_ZERO_GEN 0x38
#define REG_STATUS   0x40
#define REG_CTRL     0x41
#define REG_COUNTER  0x42
#define REG_REQUEST  0x44  // Readings requested, uint16 LE, writable: chips held powered for this many readings
#define REG_CONFIG   0x46
#define REG_REPORT   0x47
#define REG_RANGE    0x48
#define REG_SIGNAL   0x4A
#define REG_ACCEL    0x50
#define REG_ACCEL_TEMP 0x56
#define REG_ZERO_GEN_MIRROR 0x58
#define BIT_READY    0x01
#define BIT_PANFAULT 0x80
#define BIT_TRIGGER  0x01
#define CHIP_LIDAR   0x02   // control bit 1 = chip 0
#define CHIP_ACCEL   0x04   // control bit 2 = chip 1
#define BIT_SLEEP    0x80
#define FAULT_LIDAR_TIMEOUT 0x02   // chip 0, kind 2
#define FAULT_LIDAR_NOACK   0x01   // chip 0, kind 1: never acknowledged after power-up
#define FAULT_LIDAR_NOTINIT 0x05   // chip 0, kind 5: acknowledged but never reported healthy
#define FAULT_ACCEL_NOACK   0x21   // chip 1, kind 1
#define NOTICE_UNIT_RESET   0xE6   // unit (7), kind 6: reset since the controller last wrote Control (a notice: no status bit)
#define NOTICE_UNIT_PAGE0   0xE3   // unit (7), kind 3: Page 0 CRC did not match (unprovisioned or corrupt)
#define NOTICE_ACCEL_CALIBRATED 0x29 // chip 1, kind 9: a zero was stored (Page 1 holds it)
#define NOTICE_BATCH_ABANDONED  0x0A // chip 0, kind 10: the controller stopped triggering and the LiDAR was powered down

// What one acquisition has to say for itself. A fault means the chip's data are
// not to be trusted, and the chip's Status bit is set; a notice reports
// something the controller should know while the data still stand. Declared
// here, ahead of every function, because the Arduino build writes its own
// prototypes at the first function definition.
struct Acquisition {
  uint8_t Report;  // A Report code, or 0 when there is nothing to report
  bool Fault;
};

// One chip on the board: the bit that selects it in Control and marks it in
// Status, and the one function that reads it.
struct Chip {
  uint8_t Bit;
  Acquisition (*Acquire)(void);
};

// Register array: three 32-byte pages (NW-Device-Specification). Page 0
// (0x00–0x1F) identity, Page 1 (0x20–0x3F) calibration, Page 2 (0x40–0x5F)
// status and sensor data. A controller writes a start address, then reads
// up to 32 bytes with auto-increment (see requestEvent).
#define REG_SIZE 96
uint8_t reg[REG_SIZE] = {0};  // Page 0 filled by loadPage0(); Page 1 by loadPage1() at boot and after each zero; Page 2 at runtime

// A reading is assembled here and copied into reg with the counter, so a page
// read never sees half of one (the specification's atomic-rewrite rule). The
// span is 0x48 to 0x57: every byte a reading writes, and no more. The zero
// generation mirror at 0x58 is deliberately outside it, because a reading never
// writes that - a stored zero does, already with interrupts disabled - and a
// wider copy would overwrite it with stale buffer.
//
// splitAndLoad() indexes Staged[Pos - DATA_BASE] with no bound of its own, so a
// DATA_LEN shorter than the writes reach corrupts whatever follows the buffer
// and the registers never see the values at all. That is what happened on the
// Walrus firmware with DATA_LEN 10 against writes reaching 24.
#define DATA_BASE 0x48
#define DATA_LEN  16
uint8_t Staged[DATA_LEN] = {0};
bool page0Valid = false;      // Page 0 CRC matched what NW-Provision wrote

static uint8_t hexNibble(char c) {  // One hex digit to its value; 0 for anything else
  if(c >= '0' && c <= '9') return c - '0';
  if(c >= 'a' && c <= 'f') return c - 'a' + 10;
  if(c >= 'A' && c <= 'F') return c - 'A' + 10;
  return 0;
}

// Page 0 Block 3: bytes 0x18-0x1B from the first 8 hex digits of FW_COMMIT, and bit 0
// of 0x1C when it ends in '+' (a dirty tree). A blank FW_COMMIT leaves the zeros.
void fwCommitInto(uint8_t* b) {
  const char* c = FW_COMMIT;
  uint8_t n = 0;
  while (c[n]) n++;
  if(n < 8) return;
  for (uint8_t i = 0; i < 4; i++) b[i] = (hexNibble(c[2*i]) << 4) | hexNibble(c[2*i + 1]);
  b[4] = (c[n - 1] == '+') ? 0x01 : 0x00;
}

// CRC-8/SMBUS (poly 0x07, init 0x00), the NW-Device-Specification reference.
uint8_t crc8(const uint8_t* data, uint8_t len) {
  uint8_t crc = 0x00;
  for (uint8_t i = 0; i < len; i++) {
    crc ^= data[i];
    for (uint8_t b = 0; b < 8; b++) crc = (crc & 0x80) ? (crc << 1) ^ 0x07 : (crc << 1);
  }
  return crc;
}

// Copy Page 0 from EEPROM into the served register array, check its CRC,
// then substitute this firmware's patch version at 0x0A and recompute the
// CRC of the served copy (EEPROM is left as provisioned).
void loadPage0() {
  for (uint8_t i = 0; i < 32; i++) reg[i] = EEPROM.read(PAGE0_BASE + i);
  page0Valid = (crc8(reg, 0x1E) == reg[0x1E]) && reg[0x00] == 0x01;
  reg[0x0A] = FW_FW_PATCH;
  // Build identity (Block 3): the first four bytes of the git commit this firmware was
  // built from, and bit 0 of 0x1C for a dirty tree, when the build wrapper defined
  // FW_COMMIT; zeros otherwise (an IDE build). EEPROM keeps zeros there.
  fwCommitInto(reg + 0x18);
  reg[0x1E] = crc8(reg, 0x1E);
}

// Copy Page 1 from EEPROM into the served register array byte for byte, with
// every blank word (0xFFFF, never written) served as 0, and mirror the zero
// generation into Page 2 (0x58-0x59). Called at boot and after a zero is
// stored; the copy into the array is atomic so a page read never straddles it.
void loadPage1() {
  uint8_t page[32];
  for(uint8_t i = 0; i < 32; i += 2) {
    page[i] = EEPROM.read(PAGE1_BASE + i);
    page[i + 1] = EEPROM.read(PAGE1_BASE + i + 1);
    if(page[i] == 0xFF && page[i + 1] == 0xFF) { page[i] = 0; page[i + 1] = 0; } //blank word reads as 0
  }
  cli();
  for(uint8_t i = 0; i < 32; i++) reg[REG_OFFSET + i] = page[i];
  reg[REG_ZERO_GEN_MIRROR] = page[REG_ZERO_GEN - REG_OFFSET];
  reg[REG_ZERO_GEN_MIRROR + 1] = page[REG_ZERO_GEN - REG_OFFSET + 1];
  sei();
}

// Registers a controller may write. Everything else is read-only and writes
// to it are ignored (NW-Device-Specification, Page 2 rules).
bool isWritable(uint8_t pos) {
  return pos == REG_CTRL || pos == REG_CONFIG || pos == REG_I2C_ADDR
      || pos == REG_REQUEST || pos == REG_REQUEST + 1;
}
// bool startReading = true; //Flag used to start a new converstion, make a conversion on startup
// const unsigned int updateRate = 5; //Rate of update

SlowSoftI2CMaster si = SlowSoftI2CMaster(PIN_A2, PIN_A3, true);  //Initialize software I2C

volatile bool stopFlag = false; //Used to indicate a stop condition 
volatile uint8_t regID = 0; //Used to denote which register will be read from
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
void loop() {
  // static unsigned int Count = 0; //Counter to determine update rate
  // if(startReading == true) {
  //  //Read new values in
  //  AutoRange_Vis();  //Run auto range
  //  delay(800); //Wait for new sample
  //  splitAndLoad(0x0B, GetALS()); //Load ALS value
  //  splitAndLoad(0x0D, GetWhite()); //Load white value
  //  splitAndLoad(0x02, long(GetUV(0))); //Load UVA
  //  splitAndLoad(0x07, long(GetUV(1))); //Load UVB
  //  splitAndLoad(0x10, GetLuxGain()); //Load lux multiplier 
  //  splitAndLoad(0x13, GetADC(0));
  //  splitAndLoad(0x15, GetADC(1));
  //  splitAndLoad(0x17, GetADC(2));

  //  startReading = false; //Clear flag when new values updated  
  // }
  // if(Count++ == updateRate) {  //Fix update method??
  //  startReading = true; //Set flag if number of updates have rolled over 
  //  Count = 0;
  // }

  // for(int i = 0; i < 128; i++) {
  //  si.i2c_start((i << 1) | WRITE);
  //  Serial.print(i, HEX);
  //  Serial.print('\t');
  //  Serial.println(si.i2c_write(0xFF)); //Write MSB
  //  si.i2c_stop();
  // }
  // while(digitalRead(7), LOW); //Wait for updated values //DEBUG!
  // readByte(ACCEL_ADR, 0x27);
  // readWord(ACCEL_ADR, OUT_X_ADR);
  // Idle until the controller triggers (on-demand only; no free-running cycle).
  while(!(reg[REG_CTRL] & BIT_TRIGGER)) {
    set_sleep_mode(SLEEP_MODE_IDLE);   // I2C address match wakes the core
    sleep_enable();
    sei();
    sleep_cpu();
    if(zeroRequested || (!digitalRead(HALL_SWITCH) && !switchLatch)) {  //Magnet at boot, or newly applied: one application is one zero
      zeroRequested = false;
      if(!digitalRead(HALL_SWITCH)) switchLatch = true; //latch switch until toggle of state
      digitalWrite(STAT_LED, HIGH); //Turn on status LED while the zero is being taken; off once it is stored. The magnet may leave at once
      if(zeroAccel()) { updateOffset(accelVals, accelTemp); latchNotice(NOTICE_ACCEL_CALIBRATED); } //As many samples as the zero needs; nothing stored if the accelerometer failed
      digitalWrite(STAT_LED, LOW);
    }
    if(digitalRead(HALL_SWITCH)) {
      switchLatch = false; //If switch is high, back to default state, reset latch 
    }
    // if(Serial.available() > 0) {  //FIX add serial control??
    //  uint8_t Data1 = Serial.read();
    //  uint8_t Data2 = Serial.read();
    //  if(Data2 == 'F') Ctrl = Data1; //If 
    // }
    if(lidarOn && (millis() - lidarLastReading) > lidarBatchTimeout) {
      lidarPowerDown(); // batch abandoned: the controller stopped triggering
      latchNotice(NOTICE_BATCH_ABANDONED);
    }
  }
  sleep_disable();
  lidarConfig = reg[REG_CONFIG] & 0x03; //Pull low two bits from Config (0x46) to get Lidar configuration state
  // A reading begins: clear ready, take the chip selection, consume the trigger.
  reg[REG_STATUS] &= ~BIT_READY;
  uint8_t selected = reg[REG_CTRL]; // Taken once: a controller write partway through must not change what this reading holds
  reg[REG_CTRL] &= ~(BIT_TRIGGER | BIT_SLEEP); // trigger consumed; sleep not implemented
  // Seed the staged reading from what is already served, so a chip Control did
  // not select keeps its last values instead of publishing zeros. Both Walrus
  // chips write every reading and need no seed; an Apis selects its two apart.
  memcpy(Staged, reg + DATA_BASE, DATA_LEN);
  if(requestWritten) { // a new readings-requested word: count from this reading
    requestWritten = false;
    requested = reg[REG_REQUEST] | (reg[REG_REQUEST + 1] << 8);
    requestBase = reg[REG_COUNTER] | (reg[REG_COUNTER + 1] << 8);
    lidarInitFail = 0; // a new batch gets a fresh power-up attempt
  }
  // Each chip Control selects, in turn, and whatever its acquisition reports.
  // A fault marks the chip in Status; a notice does not.
  uint8_t status = BIT_READY;
  for(uint8_t chip = 0; chip < CHIP_COUNT; chip++) {
    if((selected & Chips[chip].Bit) == 0) continue; // Not selected in Control
    Acquisition Result = Chips[chip].Acquire();
    if(Result.Report) reg[REG_REPORT] = Result.Report;
    if(Result.Fault) status |= Chips[chip].Bit;
  }

  // Reading complete: load status and fault, bump the counter, set ready.
  // Atomic so a controller's page read never straddles the update.
  if (status & 0x7E) status |= BIT_PANFAULT;
  uint16_t count = reg[REG_COUNTER] | (reg[REG_COUNTER + 1] << 8);
  count++;
  cli();
  memcpy(reg + DATA_BASE, Staged, DATA_LEN); // The whole reading appears at once, with its counter
  reg[REG_COUNTER] = count & 0xFF; reg[REG_COUNTER + 1] = count >> 8;
  reg[REG_STATUS] = status;
  sei();
  // Serial.println(readByte(LIDAR_ADR, 0x0E)); //DEBUG! //READ RSSI
  // Serial.println(readByte(ACCEL_ADR, 0x27), BIN); //DEBUG! 
  // Power decision: down after a single reading (requested 0 or 1) or once the
  // requested count is done; otherwise stay powered for the next trigger.
  uint16_t done = count - requestBase;
  bool batchOver = (requested <= 1) || (done >= requested);
  if(lidarOn) {
    if(batchOver) lidarPowerDown();
    else lidarLastReading = millis();
  }
  if(batchOver) lidarInitFail = 0; //The next batch (or single reading) tries the power-up again
  // while(Serial.available() < 1 && digitalRead())
}

// float getAngle(uint8_t Axis)
// {
//  float ValX = getG(0); //Used to get g values
//  float ValY = getG(1);
//  float ValZ = getG(2);
//   float Val = 0;
//   switch(Axis) {
//     case(0):
//       Val = asin(ValX); 
//       break;
//     case(1):
//       Val = asin(ValY);
//       break;
//     case(2):
//       Val = acos(ValZ);
//       break;
//     case(3):
//       Val = atan(ValX/(sqrt(pow(ValY, 2) + pow(ValZ, 2))))*(180.0/3.14); //Return pitch angle
//       break;
//     case(4):
//       Val = atan(ValY/(sqrt(pow(ValX, 2) + pow(ValZ, 2))))*(180.0/3.14); //Return roll angle
//       break;
//   }
//   if(ValX == ValY && ValX == ValZ) Val = -9999; //Return error value is all vals are the same (1 in 6.87x10^10 likelyhood of occouring without error)
//   return Val; 
// }

uint8_t initAccel() 
{
  // writeByte(ACCEL_ADR, CTRL_REG1_ADR, 0x07);
  writeByte(ACCEL_ADR, CTRL_REG1_ADR, 0x27); //10 Hz output data rate (5 Hz bandwidth: 0.5 mg rms per sample instead of 3 mg at 400 Hz); was 0x77 //FIX! Set to low power initally??
  writeByte(ACCEL_ADR, CTRL_REG4_ADR, 0x88); //Turn on high resolution mode //FIX! Setup to use self text
  writeByte(ACCEL_ADR, CTRL_REG3_ADR, 0x10);
  writeByte(ACCEL_ADR, TEMP_CFG_REG_ADR, 0xC0); //ADC and temperature sensor on (was 0x80, ADC only): OUT_ADC3 carries the chip temperature for a drift correction
}

float getG(bool Set)  //FIX! Add offset support //By default set/send data to registers 
{ 
  // uint8_t AxisADR = OUT_X_ADR + 2*Axis; //Add appropriate offset
  // int16_t Data = readWord(ACCEL_ADR, AxisADR);
  // return Data*(4.0/4096.0); //FIX! Make fixed integer! 
  // Command |= 0x80; //turn on auto increment //FIX!!! Remove for other I2C transactions 
  bool OutOfRange = false; //Used to test if values are within expected range
  int16_t Axis[3] = {0}; //Initalize variables for x,y,z values

  bool Error = sendCommand(ACCEL_ADR, OUT_X_ADR | 0x80);
  si.i2c_stop(); 

  uint8_t Data[6] = {0}; //Init data
  si.i2c_start((ACCEL_ADR << 1) | READ);
  for(int i = 0; i < 6; i++) {
    Data[i] = si.i2c_read(i == 5); //NACK the last byte, as the bus expects
  }
  si.i2c_stop();
  for(int i = 0; i < 3; i++) {
    Axis[i] = (((int16_t)(Data[2*i + 1] << 8) | (int16_t)Data[2*i]) >> 4);
  }

  if(Error == false || OutOfRange) {  //If read error occours 
    accelFail = true; //Set flag
    Axis[0] = -9999;
    Axis[1] = -9999;
    Axis[2] = -9999;
  }
  else {  //Otherwise load/send data normally 
    accelFail = false; //Clear flag
    for(int i = 0; i < 3; i++) accelVals[i] = Axis[i]; //Copy local raw axis data to accel vals
    accelTemp = readAccelTemp(); //The chip temperature beside the axes, for the drift correction

    if(Set) {  //If sending data is commanded, print data out
#ifdef APIS_DEBUG
      Serial.print('X'); Serial.println(Axis[0] - offsets[0]);  //FIX! Optimize to prevent multiple addition 
      Serial.print('Y'); Serial.println(Axis[1] - offsets[1]);
      Serial.print('Z'); Serial.println(Axis[2] - offsets[2]);
#endif

      splitAndLoad(REG_ACCEL, Axis[0]);  //Load accel values
      splitAndLoad(REG_ACCEL + 2, Axis[1]);
      splitAndLoad(REG_ACCEL + 4, Axis[2]);
      splitAndLoad(REG_ACCEL_TEMP, accelTemp);
    }
  }


  // return Data;
}
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

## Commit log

2026-05-11 Add ready flag (Reg[0]) and document full I2C register map
    Reg[0] is set to 0 at startup and whenever POWER_SW cuts power to the
    LiDAR Lite, then set to 1 after InitLiDAR() completes. The Apis library
    polls this register (up to 150 ms) so it can exit as soon as the device
    is ready rather than waiting a fixed time.
    Also documents the complete register map (0x00–0x0F) and the startup
    timing rationale: TLV61220 EN is tied to VIN+ so the boost converter is
    always running; the 150 ms covers delay(10) + POWER_SW + cap charge
    (~15 ms at MIC2544 current limit) + delay(100) + ENABLE + init ≈ 115 ms.
    Closes: https://github.com/NorthernWidget-Skunkworks/Project-Symbiont-LiDAR/issues/15
    Co-Author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
    [Apis_LiDAR_Firmware.ino]
2026-05-11 Clean up LiDAR_Interface.ino header and comments
    Remove erroneous //Dyson_Driver_ShortWave.ino title (copy-paste artifact).
    Add spacing and section comments for Commands and Pin definitions blocks.
2026-05-11 Note that 0x41 address requires a board revision; ADR_SEL_PIN not wired
    JP1 is the MIC2544 current-limit jumper, not an address jumper. No
    address-selection hardware exists in the current board revision.
    Documents planned EEPROM-based address selection as the software path.
2026-05-13 Expand register map to 32 bytes (v0.2.0 firmware)
    Breaking change: requires Apis_Library v0.2.0. Old library will fail
    begin() name check and return false.
    Register map changes:
    - Reg[16] -> Reg[32]; statically initialise name ('A','p','i','s'),
    HW version (0x05-0x06), and FW patch (0x07) bytes
    - Config: 0x01 -> 0x0B
    - Range: 0x02-0x03 -> 0x08-0x09
    - Signal strength: new at 0x0A (LiDAR Lite reg 0x0E, inline read)
    - Accel raw: 0x04-0x09 -> 0x10-0x15
    - Accel offsets: 0x0A-0x0F -> 0x18-0x1D
    Other changes:
    - Add FW_HW_MAJOR/FW_HW_MINOR/FW_FW_PATCH version constants (0, 1, 0)
    - setup(): read EEPROM byte 6 for persistent I2C address before Wire.begin()
    - receiveEvent(): write to EEPROM byte 6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
    [Apis_LiDAR_Firmware.ino]
2026-05-13 Update stale Symbiont-LiDAR references in README
    - Fix library link: NorthernWidget-Skunkworks/Symbiont-LiDAR_Library
    -> NorthernWidget/Apis_Library
    - Update section heading and example code: SymbiontLiDAR.h -> Apis.h,
    SymbiontLiDAR class -> Apis class, in all three code examples
    - Replace "Symbiont board/box/unit" with "Apis board/box/unit" in
    assembly instructions and photo captions
    - Leave Former/Symbiont-LiDAR history section and unverified
    NorthernWidget-Skunkworks links untouched (see issue #20)
    Closes #20.
2026-05-13 Expand README: table of contents, assembly guide, register map section
    - Add table of contents (H2/H3 depth)
    - Replace draft THOUGHT note with full PCB assembly guide (producing,
    populating, reflowing, debugging), adapted from Project-Walrus
    - Add register map and firmware internals section: measurement loop,
    32-byte register table, sensitivity modes, persistent I2C address,
    and firmware compatibility/detection via begin()
    - Update stale firmware references (LiDAR_InterfaceDemo → Apis_LiDAR_Firmware)
    - Remove UPDATE CODE reminder from Margay example comment
2026-05-13 Add new photos; place assembled unit and board images in README
    - Apis_v010_assembled_front_20250206.jpg: hero shot of assembled unit
    showing PITCH/ROLL markings and Hall-effect zero location on box face
    - Apis_v010_board_top_20250206.jpg: clean top-side board photo with
    quarter for scale
    - Assembled unit photo placed in Technical specifications (overview) and
    below pitch/roll diagrams at step 11, replacing the >> Hall-effect note
    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
2026-05-31 Update register map: show current and proposed Schema 1 layouts side by side
    Current firmware (prototype) and proposed NW-Device-Specification Schema 1
    layout are now both documented. Proposed layout uses three 32-byte pages
    (Page 0 identity/EEPROM, Page 1 sensor data/SRAM, Page 2 calibration/EEPROM)
    and is marked as not yet implemented in firmware.
2026-06-01 README: add NW-Device-Specification Schema 1 Page 0 block
    Documents the device's 32-byte EEPROM identity block per
    https://github.com/NorthernWidget/NW-Device-Specification
2026-06-01 Page 1 status byte: add pan-fault (bit 7), label 0x27 as extended fault byte
    Reflects the NW-Device-Specification Schema 1 standard: bit 7 is the
    pan-fault summary (set when any bit 1–6 is set); 0x27 is reserved as
    the extended fault byte and must be written as 0x00.
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2026-09-21 README: Page 1 follows the spec's universal Block 0; device data from 0x28; chip table
    Claude-Session: https://claude.ai/code/session_017NLdTS5Fho8nG3ih9RPxSQ
2026-09-21 Firmware: camelCase for functions and globals (no behaviour change)
    Per the NW convention that firmware follows Arduino style like the
    libraries: readByte, writeByte, readWord, readWordLE, writeWordLE,
    sendCommand, splitAndLoad, initAccel, initLiDAR, getRange, getG,
    updateOffset, getOffsets; globals timeoutGlobal, lidarFail, accelFail,
    adr, config, period, reg, stopFlag, regID, repeatedStart, offsets,
    accelVals, switchLatch, lidarConfig. Macros and local variables are
    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
2026-09-21 Firmware: 96-byte register array; requestEvent serves a full page with auto-increment; writes gated
    reg[] grows from 32 to 96 bytes (Pages 0-2). requestEvent() loads 32
    bytes from the requested register, wrapping within the array, so a
    controller can read a page in one transaction as NW-Device-Specification
    describes; WireS clocks out only what is asked for. receiveEvent()
    ignores writes to any register but the writable ones (still 0x0B config
    and 0x0C address in this commit; they move with the Schema 1 layout next).
    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
2026-09-21 Firmware: Page 1 in the Schema 1 layout with the universal Block 0
    Status at 0x20 (ready, LiDAR fault, accelerometer fault, pan-fault),
    control at 0x21 (trigger, per-chip select, sleep bit reserved and
    cleared), reading counter at 0x22-0x23, config at 0x26, latched fault
    code at 0x27 cleared by a control write. Range and signal strength move
    to 0x28-0x2A, accelerometer axes to 0x30-0x35, offsets to Page 2 at
    0x40-0x45.
    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
2026-09-21 Firmware: Page 0 identity from EEPROM; I2C address from 0x1F; boot fault code
    loadPage0() copies the top 32 bytes of EEPROM (0xE0-0xFF, written by
    NW-Provision) into the served register array, checks the CRC-8/SMBUS,
    writes this firmware's patch version at 0x0A, and recomputes the CRC of
    the served copy; EEPROM is left as provisioned. The compiled-in name and
    hardware version go away. The I2C address is Page 0 byte 0x1F, default
    0x41 ('A', Schema 1) when unprogrammed; a write to register 0x1F persists
    it with compare-before-write. At boot the fault byte is set to "unit:
    reset since last control write", or "unit: Page 0 checksum" when the CRC
    fails, latched until the controller first writes C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
    [Apis_LiDAR_Firmware.ino]
2026-09-21 Firmware: accelerometer offsets stored at the Page 2 EEPROM location (0xC0)
    Page 2 (calibration) sits immediately below Page 0 in EEPROM per
    NW-Device-Specification; the offsets move there from bytes 0-5 and are
    written with compare-before-write. A never-written offset (0xFFFF) reads
    as zero, so a board reflashed with this firmware starts unoffset and is
    re-zeroed with the magnet; no migration from bytes 0-5 (decided
    2026-09-21). Nothing else uses EEPROM below 0xC0 now.
    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
2026-09-21 README: board type is 0x4100 (hardware major 0), matching the spec, NW-Registry and NW-Provision; fold the duplicate Page 0 section
    The register-map section said revision index 1; NW-Provision computes
    board_type = ('A' << 8) | hw_major, and Apis hardware is v0.1, so the
    byte is 0x00, as the spec appendix and NW-Registry already say. The
    trailing "Schema 1, Page 0" section repeated the register map with the
    stale 0x00 magic byte; it is replaced by a short legacy-identity note.
    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
2026-09-21 Firmware: accelerometer status wait — timeout guards the whole condition; accelFail set on timeout, not on success
    The wait condition mixed || and && without parentheses, so the timeout
    applied only to the Stat2 half and a stuck Stat1 could wait forever; and
    the flag afterwards was set when the wait had NOT timed out. Both are
    from Project-Apis #22. The flag is still overwritten by getG() when the
    accelerometer is read, but stands on its own when the accelerometer is
    deselected through the control register, which the Schema 1 library can
    do. Compiles for the ATtiny1634; the parentheses warning is gone.
    See #22.
    Claude-Session: http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
    [Apis_LiDAR_Firmware.ino]
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2026-09-22 Firmware: on-demand run model driven by the readings-requested word (0x24-0x25)
    The unit now idles until a trigger; the free-running 100 ms cycle is
    gone. The LiDAR is powered up at the first trigger and powered down
    when the reading counter has advanced by the requested count (0 or 1
    = one reading, powered down after it); a new write to 0x24-0x25
    replaces the remainder from the next trigger. The request word is the
    controller's number, never incremented by the device; the device
    keeps the counter value at latch time in a private variable. A burst
    with no trigger for 2 s is abandoned (LiDAR off, fault chip 0 kind 2).
    Config (0x26) changes mid-burst re-run initLiDAR(). 0x24-0x25 join
    the writ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
    [Apis_LiDAR_Firmware.ino]
2026-09-22 Firmware: LiDAR readiness by polling its STATUS register instead of a 100 ms delay
    After the 5 V switch closes, wait ~20 ms for the rail (680 uF through
    the MIC2544 at its ~227 mA limit), raise enable, then poll for an I2C
    acknowledge and the health flag (STATUS 0x01 bit 5) for up to 100 ms;
    the v3HP manual gives ~22 ms from power to first measurement. On
    timeout, toggle enable once more after another rail wait; a second
    failure powers the LiDAR down and latches chip 0 kind 1 (no
    acknowledge) or kind 5 (not initialised), and the reading completes
    with range -9999 so the controller's wait ends promptly.
    Claude-Session: https://claude.a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
    [Apis_LiDAR_Firmware.ino]
2026-09-22 Firmware: wait for the LiDAR by polling its busy bit, not the mode pin
    getRange() waited for MODE_READ to go high, but the schematic holds
    that net high through R11 (1 kOhm) from MODE_TRIGGER, so the loop
    never waited and the distance registers were read while the
    acquisition ran (the manual: that returns the previous measurement).
    Now poll STATUS (0x01) bit 0 until clear, as Garmin's own library
    does. ACQ_COMMAND 0x01 is correct on the v3HP (any non-zero value).
    See Project-Apis #23 and #24.
    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
    [Apis_LiDAR_Firmware.ino]
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2026-09-22 Firmware: a failed LiDAR power-up is not retried on every trigger of the same burst
    The remaining readings of the burst report the latched fault at once,
    so a burst on a LiDAR that will not power up costs ~10 ms per reading
    (accelerometer only) instead of ~440 ms. A new readings-requested
    word, or the end of the burst, allows the next power-up attempt;
    single readings always retry.
    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
    [Apis_LiDAR_Firmware.ino]
2026-09-22 Firmware and README: "batch" for a declared run of readings (rename only)
    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
    [LiDARLite_Symbiont.SLDPRT, LiDARLite_Symbiont_Mount.DXF]
2026-09-23 Documentation: Benewake TF-series evaluated as a LIDAR-Lite v3HP replacement (research note, no decision)
    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
2026-09-23 Firmware: restore Bobby's dropped notes and wording; new lines in his form
    The loop restructure (c3e5719) dropped four of his commented-out
    lines (the RSSI and accelerometer-status debug reads, the "FIX add
    serial control??" block, the trailing while); back where they stood.
    His "(new application of trigger)" and the commented AutoRange_Vis()
    name were mine to leave alone; reverted. My new lines now use his
    "if(" form and his unaligned "//comment" trailers. Compiles at the
    same size. Found by the 2026-09-23 voice audit.
    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
    [Apis_LiDAR_Firmware.ino]
2026-09-23 Firmware patch 3: accelerometer at 10 Hz, its temperature served, a Hall zero that samples until settled
    Andy, 2026-09-23: enable the temperature sensor for correction; measure at
    10 Hz; let the calibration with the magnet present take as much time as it
    needs for the best possible zero.
    CTRL_REG1 0x27 (10 Hz, 5 Hz bandwidth: about 0.5 mg rms per sample instead
    of 3 mg at the former 400 Hz). TEMP_CFG_REG 0xC0 turns the LIS3DH's own
    temperature sensor on; its OUT_ADC3 word is read with every reading and
    served at 0x36-0x37 (relative, 1 digit per degree in the high byte), the
    reference a per-unit drift correction needs. The Hall zero no longer stores
    one sample: with the magnet held it takes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
    [Apis_LiDAR_Firmware.ino]
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2026-09-23 Firmware: the magnet only starts the zero; at boot a momentary magnet is enough
    Andy, 2026-09-23: the magnet needs only be momentarily present during the
    boot sequence. A magnet seen at boot now requests a zero that runs once
    the firmware is idle, and a zero no longer stops when the magnet leaves:
    the LED stays on until the averaged zero and its temperature are stored.
    The boot-time behaviour before this (clear the offsets to zero) is gone;
    a zero replaces the old one, and a failed accelerometer read leaves it.
    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
    [Apis_LiDAR_Firmware.ino]
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2026-09-23 Firmware patch 5: a record of the zeros on Page 1 (ring of two, generation), mirrored at 0x58
    Storing a zero shifts Block 1 to Block 2 and Block 0 to Block 1 before
    the new zero is written into Block 0, and adds one to the generation at
    0x38-0x39 (blank 0xFFFF reads as 0), all with EEPROM.update byte by
    byte. loadPage1() serves Page 1 from EEPROM byte for byte with every
    blank word as 0 and mirrors the generation into 0x58-0x59, at boot and
    after each zero; getG() no longer rewrites the offsets into the page.
    Page 1 is now stored in bus order (little-endian words): the writer and
    reader agreed on big-endian before, while the boot copy served the bytes
    as stored, so a unit zeroed under patch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
    [Apis_LiDAR_Firmware.ino]
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2026-09-24 Firmware: stop forcing the auto-increment bit on every single-byte read
    readByte() OR-ed 0x80 into the register address for every chip. That is the
    LIS3DH's auto-increment flag - "SUB(7) must be equal to 1 while SUB(6-0)
    represents the address field" - and it is meaningless on the LIDAR-Lite v3HP,
    whose manual says the device "auto-increments the register address with
    successive reads or writes within an I2C block transfer" with no flag at all.
    So every LiDAR read through this helper addressed register 0x81 rather than the
    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
    [ApisMountPlate2025_v2.FCStd]
2026-09-24 Firmware: start a LiDAR measurement with 0x04, as the manual specifies
    ACQ_COMMAND (register 0x00) is a split register in the v3HP manual. Bits 7:1
    are "write any non-zero value to start a measurement". Bit 0 "performs a hard
    reset by reloading the FPGA", and acts only once it has been enabled by writing
    1 to bit 0 of LEGACY_RESET_EN (0x06).
    The firmware wrote 0x01: nothing in bits 7:1, so no measurement, and a request
    for a reset that is disabled because 0x06 is never written. The manual's own
    worked sequence writes 0x04, which is what is used here now.
    This line has been in the firmware since its first commit, so if an Apis has
    ever returned a good range on hardware then the part is more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
    [Apis_LiDAR_Firmware.ino]
2026-09-24 Firmware: acknowledge every byte of a read but the last one
    I2C wants the controller to NACK the final byte it reads, which is how a
    peripheral is told the transfer is over; an ACK says "send me another" and is
    then followed by a STOP instead. SlowSoftI2CMaster spells this i2c_read(last),
    where true releases SDA to NACK and false pulls it down to ACK.
    Six reads acknowledged their last byte: the accelerometer's six-byte burst, the
    LiDAR's signal strength (a single byte, so the first is also the last), both
    sixteen-bit helpers, the accelerometer temperature word, and the unused
    three-argument readByte, which is corrected with the rest rather than left as a
    trap. The single-byte readByte alrea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
    [Apis_LiDAR_Firmware.ino]
2026-09-24 Firmware: stop forcing the auto-increment bit on writes as well
    The same defect as in readByte, in writeByte, with the same FIX!!! comment
    beside it - and this one mattered more, because it silently undid the previous
    correction.
    Every LiDAR write went to the wrong register: configuration 0x02, 0x04, 0x12
    and 0x1C became 0x82, 0x84, 0x92 and 0x9C, and ACQ_COMMAND 0x00 became 0x80. So
    the measurement command could never start a measurement whatever value it
    carried, which means writing 0x04 instead of 0x01 had no effect on its own.
    Both changes are needed for either to do anything.
    As with the read path, no caller needs the bit: every writeByte call writes a
    single register, on the LiDAR an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
    [Apis_LiDAR_Firmware.ino]
2026-09-24 Revert "Firmware: stop forcing the auto-increment bit on writes as well"
    This reverts commit bdea5787eacc9bbd0a2623c32e16d707bdca5f02.
    [Apis_LiDAR_Firmware.ino]
2026-09-24 Revert "Firmware: stop forcing the auto-increment bit on every single-byte read"
    This reverts commit 398a7aa4d6c6b9b33ff89adcbd95dc0148376e89.
    [ApisMountPlate2025_v2.FCStd]
2026-09-24 Revert "Firmware: start a LiDAR measurement with 0x04, as the manual specifies"
    This reverts commit ce008d9286e17504bd686c10b52a6a3c5eebbfb6.
    [Apis_LiDAR_Firmware.ino]
2026-09-24 Firmware: record what ACQ_COMMAND actually does, rather than a partial reading
    The comment I added on 2026-09-22 quoted the manual's "write any non-zero value
    to start a measurement" as though it described the whole register. It describes
    bits 7:1. Bit 0 is a hard reset, gated behind LEGACY_RESET_EN (0x06), which this
    firmware never writes.
    Read strictly, the 0x01 this firmware has always sent carries nothing in bits
    7:1 and should start nothing. Units measure, so the part triggers on any
    non-zero write and the manual's bit split is tighter than the silicon. That is
    the fact worth recording, because it is what stops the next reader - or me -
    "fixing" a working line from the manual alone.
    C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
    [Apis_LiDAR_Firmware.ino]
2026-09-24 Firmware: mark ACQ_COMMAND as an open bench question, not a settled one
    The comment I wrote an hour ago asserted that "units do measure, so the part
    triggers on any non-zero write". I had no evidence for that. It was inferred
    from a question about why the firmware worked, and written down as though it
    were a measurement.
    Reading the manual's pages properly - rather than the flattened two-column text
    that misled me the first time - the register split is exactly as stated: bits
    7:1 start a measurement, bit 0 is a hard reset gated behind LEGACY_RESET_EN,
    which this firmware never writes. So 0x01 should start nothing, and the manual's
    worked sequence uses 0x04.
    What is genuinely unknown is whe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
    [Apis_LiDAR_Firmware.ino]
2026-10-01 One function per chip: acquireLidarLiteV3HP() and acquireLIS3DH()
    The last firmware owing LIBRARY-DESIGN.md section 13. The reading path knew both
    chips at once: it read the chip-select bits into two booleans, interleaved a
    rangefinder power-up, an accelerometer status poll, an offsets read and two
    acquisitions, and then tested those booleans again in a third place to record
    faults.
    Each chip now has one function that selects it, acquires once, and publishes
    everything that acquisition produced. It returns an Acquisition: the Report code,
    and whether that report is a fault (the chip's data are not to be trusted, so
    Status marks it) or a notice. A table of chips and a five-line loop replace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
    [Apis_LiDAR_Firmware.ino]
2026-10-01 Atomic rewrite: a reading is staged and appears all at once
    The specification requires it of every device (README.md, Page 2 Block 0: "Your
    device must rewrite the data registers and increment the counter with interrupts
    disabled, so that a page read never straddles a rewrite"). Walrus and Libelle do;
    Apis wrote its data registers directly as each chip was acquired, with only the
    counter and status byte under cli().
    The failure that closes, which the counter seqlock does not: a controller whose
    page read begins and ends inside one acquisition window sees a half-updated page
    with an unchanged counter, so its re-check says "consistent" and it keeps a mix
    of this reading and the last. The LiDA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
    [Apis_LiDAR_Firmware.ino]
